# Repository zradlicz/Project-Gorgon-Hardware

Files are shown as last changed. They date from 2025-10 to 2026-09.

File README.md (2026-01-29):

# SDI-12 Underground Temperature Sensor

A 7-channel 4-wire RTD temperature measurement device that communicates via the SDI-12 protocol, designed for underground temperature profiling applications.

## Overview

This device is an SDI-12 sensor that provides high-precision temperature measurements from seven 4-wire RTD (Resistance Temperature Detector) inputs. It is designed for underground temperature sensing applications such as soil temperature profiling, permafrost monitoring, and geothermal studies. The 4-wire RTD configuration eliminates lead resistance errors, enabling accurate measurements even with long cable runs to buried sensors.

Built around the Raspberry Pi RP2040 microcontroller and featuring a 24-bit ADC, the sensor integrates seamlessly with existing SDI-12 data logger infrastructure.

## Features

- **7 channels** of 4-wire RTD temperature measurement
- **24-bit precision ADC** (AD7124-8) for high-resolution measurements
- **8-channel analog multiplexer** (ADG708) for RTD channel selection
- **SDI-12 protocol** compatible with standard environmental data loggers
- **RP2040 microcontroller** (dual-core Arm Cortex-M0+)
- **USB interface** for configuration and direct data access
- **128Mb flash memory** for configuration storage
- **Weatherproof enclosure** with gasket seal for field deployment

## Hardware Specifications

| Parameter | Value |
|---|---|
| RTD Channels | 7 (4-wire configuration) |
| ADC Resolution | 24-bit |
| Communication | SDI-12, USB |
| Power Supply | 5V |
| Logic Level | 3.3V (internal) |
| MCU | RP2040 (Raspberry Pi) |

## Key Components

| Reference | Part | Description |
|---|---|---|
| U7 | RP2040 | Main microcontroller |
| U8 | AD7124-8BCPZ | 24-bit 8-channel ADC |
| U5 | ADG708BRUZ | 8-channel analog multiplexer |
| U4 | W25Q128JVS | 128Mb SPI flash memory |
| U3 | TXS0102DCT | Bidirectional level shifter |
| U2 | NCP1117-3.3 | 3.3V voltage regulator |
| U1 | LP2950-5.0 | 5V voltage regulator |

## Repository Structure

```
├── sdi12-analog-mux.kicad_sch    # KiCad schematic
├── sdi12-analog-mux.kicad_pcb    # KiCad PCB layout
├── sdi12-analog-mux.kicad_pro    # KiCad project file
├── sdi12-analog-mux.step         # 3D model of assembled PCB
├── CAD/
│   ├── assembly.FCStd            # FreeCAD full assembly
│   ├── bottom_housing.FCStd      # Bottom enclosure design
│   ├── PCB.FCStd                 # PCB model
│   └── enclosure/
│       ├── Bottom.stl            # 3D printable bottom housing
│       ├── Cover.stl             # 3D printable top cover
│       ├── Gasket.stl            # 3D printable gasket
│       ├── Gasket_Drawing.dxf    # Gasket cutting template
│       └── *.step                # STEP files for CAD import
└── production/
    ├── bom.csv                   # Bill of materials
    ├── positions.csv             # Component placement data
    ├── designators.csv           # Component designators
    └── netlist.ipc               # IPC netlist
```

## Applications

- Soil temperature profiling
- Permafrost and active layer monitoring
- Geothermal gradient measurement
- Agricultural soil monitoring
- Infrastructure temperature monitoring (roads, pipelines)
- Environmental research

## Manufacturing

Production files are located in the `production/` directory:
- **BOM**: `bom.csv` contains the complete bill of materials
- **Pick and Place**: `positions.csv` provides component placement coordinates
- **Gerbers**: Included in `sdi12-analog-mux.zip`

## Enclosure

The enclosure is designed for 3D printing and field deployment:
- Bottom housing with mounting features
- Top cover
- Gasket for weatherproof sealing
- Provisions for cable glands and ventilation

STL files for printing and STEP files for CAD integration are provided in `CAD/enclosure/`.

## Design Tools

- **PCB Design**: KiCad 8
- **Mechanical Design**: FreeCAD

## License

This project is open-source hardware.

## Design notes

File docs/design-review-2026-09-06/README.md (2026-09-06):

# Lab handoff: Gorgon design and power review

Start with [DIAGNOSIS.md](DIAGNOSIS.md) for the three-board power failure and [DESIGN-REVIEW.md](DESIGN-REVIEW.md) for the broader review. These are an investigation and proposed tests, not completed repairs or a qualified design release. No physical measurements were performed by the reviewing agent.

## User-confirmed observations

- Three Gorgons connect to **separate sensor ports on one SDI-12 Talon**. With all three connected, none powers reliably and the Talon's 12 V sometimes fails to rise.
- Replacing the logger with GEMS_010 did not resolve SDI-12 read/detect/power-init failures and sensor-power warnings.
- A one-mux logger configuration briefly worked. Its exact power/data sequencing is not available here.
- Each Gorgon has an added **1000 µF input capacitor**. This was needed because the Gorgon's 3.3 V rail failed to start even on an **independent 12 V supply**. Do not assume the Talon caused that original failure.
- The user identified **CL05A106MQ5NUNC** as the assembled capacitor in the C22 discussion. It is rated 6.3 V; C22 is across +12 V and GND in the schematic, PCB and production netlist. Confirm the assembly designator and physical board revision before rework.
- The user reports the latest Talon revision. The supplied repository documents v1.4; physical markings have not been inspected.
- Four additional builds and outdoor installation before freeze in Thief River Falls are time-sensitive. A year-end deliverable is not the installation deadline.
- The changed antenna reportedly worsened cellular connectivity; no causal link to the power failure has been established.

## First lab session

1. Record physical revisions, all existing rework, fitted C22/C1 parts, deployed firmware/configuration, supply settings, and cable lengths. Photograph the regulator area if useful.
2. With power disconnected and capacitors discharged, confirm C22 continuity to J4 pin 1 (+12 V) and J4 pin 3 (GND). Replace the underrated part before further 12 V qualification; adding capacitance in parallel does not correct its voltage rating.
3. On a corrected board, compare startup with appropriate local ceramic bypassing and with the 1000 µF workaround. Capture U6 VIN and 3.3 V simultaneously, USB disconnected. A supply display is not a startup waveform.
4. Then capture Talon input 3.3 V, raw 12 V at C9, port output voltage and relevant faults during single, simultaneous-three and staged-three startup. The detailed report distinguishes the fault polarities and supply stages.
5. Validate the separate analog and firmware findings in the overall review. Do not assume every source-code finding describes the deployed binary, or that fixing power alone qualifies measurement accuracy.

For each trial, record board ID, firmware revision, exact wiring/rework, supply voltage/current limit, probe nodes, test action, captured waveform filenames, outcome and interpretation. Preserve raw measurements and distinguish observation from hypothesis. Add lab results to a new dated note alongside these reports so the original review remains traceable.

## Folder arrangement on the lab computer

Keep these repositories as siblings under any parent directory:

```text
gorgon/
  Project-Gorgon-Hardware/
    docs/design-review-2026-09-06/  <-- this handoff
  Project-Gorgon-Firmware/
  Talon-SDI12/
  Project-Kestrel/
  kistack/                       <-- optional local KiCad skills
```

Relative links in the reports follow that arrangement. Historical paths embedded in KiCad's generated reports/netlist describe the review machine; they need not exist on the lab computer. The exported PNG/SVG files are directly viewable. `render-detail.cjs` is an optional crop renderer and requires Node.js with `sharp` available; the PNG is already included.

## Source revisions reviewed

| Repository | HEAD at handoff preparation |
|---|---|
| Project-Gorgon-Hardware, before this documentation commit | `8b84860ecc22e27c8c2fa7a2cfa7f66302e375bf` |
| Project-Gorgon-Firmware | `efc0b9da459f3705718986a0e039e167b8b92fd8` |
| Talon-SDI12 | `10fa75d569e4cc0d9df58e523539647c02b93214` |
| Project-Kestrel | `4531bba269e10d33e8866283889c40a0a308d147` |

The reviewing tools used KiCad 10.0.6. DRC and ERC reports contain unresolved findings; no fabrication release was produced. Hardware repository user settings (`.kicad_prl`) were modified in the working directory and intentionally excluded from the documentation commit.

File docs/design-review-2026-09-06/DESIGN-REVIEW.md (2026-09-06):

# Gorgon design review

2026-09-06. Review of the local schematic, PCB, production netlist/BOM, firmware and calibration tool. Hardware observations apply to this checkout, not an independently inspected physical assembly. C22's fitted part number was supplied by the user. The deployed firmware version is unknown. No circuitry or firmware was modified.

## Overall assessment

The architecture is sensible: an AD7124-8 with differential four-wire RTD sensing, a shared excitation source, analog channel selection, input filtering, and an RP2040 for communication and calibration. The buck supply and external ADC are appropriate building blocks. The implementation is still at prototype maturity: there are confirmed component and firmware defects, an analog headroom problem, and unqualified field interfaces. I would not replicate the existing design unchanged for the four additional units.

Priority definitions: P1 = resolve before field qualification/build replication; P2 = resolve or explicitly qualify before deployment. Findings distinguish direct file evidence from inferred physical behavior.

## 1. P1 — C22 is overvolted: confirmed

C22 pad 1 is +12V and pad 2 is GND in schematic, PCB and production netlist. The supplied assembly part CL05A106MQ5NUNC is rated 6.3 V. Replace it; a parallel 1000 µF capacitor does not reduce its DC voltage. Specify a qualified 25 V ceramic retaining adequate capacitance under bias and temperature, with a suitable footprint. Audit C1 and other rail capacitors against the real assembly order. This is a confirmed rating violation; actual damage and its contribution to startup have not been measured. [Samsung specification](https://mm.digikey.com/Volume0/opasdata/d220001/medias/docus/41/CL05A106MQ5NUNC_Spec.pdf).

The 1000 µF workaround and three-unit Talon startup require requalification after this repair. See [power diagnosis](DIAGNOSIS.md). Preserve controlled inrush if substantial bulk capacitance remains necessary.

## 2. P1 — Excitation/reference network has insufficient margin at 500 µA

Verified current path: U8 AIN0/IOUT → U5 mux → RTD excitation lead → RTD → return diode D2–D8 → R19 5.11 kΩ → R20 250 Ω → GND. The firmware selects 500 µA at `sdi12-analog-mux.c:347`.

For a 100 Ω RTD, resistor drops alone total:

`0.0005 × (5110 + 250 + 100) = 2.73 V`.

At a nominal 3.3 V supply, the AD7124 specified current-source compliance ceiling is 2.93 V. Only **0.20 V** remains for the diode, mux, and both excitation leads. The documented 1N4148 diode replacement is very likely to exceed that allowance by itself at this current. Actual voltages need measurement; current can fall out of regulation, changing common-mode/reference conditions. A ratiometric architecture does not excuse violation of those limits.

Reducing current alone is not a complete fix: R20 lifts REFIN− only to 125 mV at 500 µA, 62.5 mV at 250 µA, and 12.5 mV at 50 µA. The code enables the reference buffers, whose lower limit is 100 mV above ground. At 50 µA, R19 develops only 0.2555 V differential reference, below the ADC's 0.5 V minimum. Thus the README's 50 µA operating description is not a valid setting for this buffered circuit as drawn.

Redesign the reference resistance, ground-lift resistance, excitation current and diode/mux topology together. Verify headroom at cold diode voltage, supply minimum, RTD maximum resistance, and longest lead resistance. Do not specify a replacement operating current without that calculation. [AD7124 datasheet, reference and current-source limits](https://www.analog.com/media/en/technical-documentation/data-sheets/ad7124-8.pdf).

## 3. P1 — Firmware turns processor temperature into RTD gain error: confirmed

`ad1724.c:309–354` treats the RP2040 temperature sensor as a fixed 0.706 V source, estimates AVDD from it, and stores `g_vref_correction`. At line 518, that factor multiplies measured RTD resistance. The sensor voltage depends on temperature and device variation, so this cannot independently measure AVDD. [RP2040 datasheet, section 4.9.5](https://datasheets.raspberrypi.com/rp2040/rp2040-datasheet.pdf).

Illustrative calculation at constant true supply: using the nominal sensor slope, a 10°C increase lowers its voltage from 0.706 V to 0.68879 V. The correction increases by `0.706/0.68879 = 1.025`. Applied to 100 Ω, that is about 2.5 Ω, approximately 6.5°C equivalent near 0°C. This is an illustration, not measured field error. Because the factor is calculated at startup, reboot temperature can change the calibration scale.

Remove or replace this correction after fixing the analog operating point and then recalibrate. If rail measurement is needed, use an actual known reference/supply-monitor method. Test precision resistors while changing board temperature separately from sensor temperature.

## 4. P1 — REFOUT is tied to the external reference sense node

Both the PCB and schematic join U8 pin 22 (REFOUT) to pin 12 (REFIN1+) on `POSITIVE_REF`, also connected through R29 to R19. This is not necessary for internally selected reference operation. `adc_read_internal_temperature()` enables the internal reference (`ad1724.c:595`), so diagnostic mode can drive a node intended to sense the external current-derived reference. The reference-measurement helper also enables it. Consequences depend on the active excitation and settling; this is a verified connection and mode interaction, not a measured contention current.

Separate REFOUT from the external reference sense network and retain its required local decoupling. Test RTD → internal-temperature → RTD transitions, including failures/timeouts. [AD7124 reference documentation](https://www.analog.com/media/en/technical-documentation/data-sheets/ad7124-8.pdf).

## 5. P1 — SDI-12 measurement acknowledgment is late: confirmed

`sdi12.c:315` calls the measurement callback before sending `atttn`. The RTD callback includes a 20 ms delay, three discarded conversions and eight averaged conversions (`sdi12-analog-mux.c:218` onward). The delay alone exceeds the permitted response-start time; sending `time_seconds = 0` after finishing does not fix this.

Send the acknowledgment promptly with an appropriate completion time, then measure asynchronously and return stored results when requested. Use a logic analyzer to validate break handling, initial response timing, line release, and data readiness. A tolerant bench logger does not establish compatibility with the Talon logger. [SDI-12 specification, section 4.4 and timing](https://www.sdi-12.org/current_specification/SDI-12%20Specification%201.4%20February%2020%202023.pdf).

## 6. P1 — TXS0102 is not a complete SDI-12 physical interface

U3 B1 directly connects to the field data terminal; OE is permanently tied high. The translator has internal pull-ups and edge accelerators. There is no explicit SDI-12 source-impedance or controlled-slew network in that connection, nor a defined receive/off-state resistance to ground. Putting the MCU GPIO in input mode does not disable U3's internal pull-ups. This is a design-level compatibility concern, independent of the missing power rail.

SDI-12 specifies 1–2 kΩ transmitter source resistance, 160–360 kΩ off resistance to ground, and limited slew rate. The current circuit does not deliberately implement those properties. Redesign around a controlled transmitter and receiver with defined idle/released states; qualify it using actual cable capacitance and powered/unpowered combinations. Do not base qualification on a generic UART speed rating. [TXS0102 datasheet](https://www.ti.com/lit/ds/symlink/txs0102.pdf), [SDI-12 electrical specification](https://www.sdi-12.org/current_specification/SDI-12%20Specification%201.4%20February%2020%202023.pdf).

## 7. P1 — Calibration tool and firmware disagree: confirmed

The firmware calibration callback explicitly uses **5030 Ω** (`sdi12-analog-mux.c:127`). The Python tool reads an existing NVM value and computes `new = old × actual/measured` (`calibrate.py:54,570`). That formula is incorrect when the firmware used 5030 rather than `old`; repeated calibration can alter gain even with identical hardware and reference resistors. Align the assumed scale and add a repeated-calibration check.

The tool also writes one averaged value to every channel (`calibrate.py:324`), whereas acquisition applies per-channel values. Save individually determined channel constants if channel correction is intended. The hardware R19 nominal is 5110 Ω, while firmware defaults are 5030 Ω; explain or eliminate that discrepancy instead of leaving conflicting nominal values.

Historical evidence: `calibration_report_007_20260306_144608.txt` shows approximately 99.8 Ω standards producing about 108 Ω, followed by an averaged effective reference of 4677.01 Ω. This is much larger than R19's stated 0.1% tolerance and cannot be attributed to that tolerance alone. The report may precede the current firmware, so it does not identify which current defect caused the historical error. Room-temperature gain correction cannot establish cold accuracy.

## 8. P2 — Internal ADC temperature conversion is incorrectly decoded

`ad1724.c:633–646` sign-extends the ADC result as two's complement. Bipolar output is offset binary; the documented temperature equation subtracts `0x800000` before division. Correct decoding and verify using a representative raw code. This affects diagnostic temperature, not directly the external RTD conversion. [AD7124 temperature equation](https://www.analog.com/media/en/technical-documentation/data-sheets/ad7124-8.pdf).

## 9. P2 — USB and field power are connected without explicit source arbitration

U2's USB-fed 3.3 V output and U6's buck output are directly joined. The schematic contains no explicit ORing or power mux. Their behavior with USB only, 12 V only, both supplies, and either supply removed must be qualified against actual fitted regulators, including reverse-current behavior. This is a verified shared connection, not proof of harmful current on every board.

Prefer explicit power selection/ORing or a documented exclusive-power service arrangement. USB-only operation also does not power U1's 5 V SDI-12 rail; do not assume USB debugging reproduces field behavior.

## 10. P2 — Outdoor connector protection is incomplete

J4 feeds the power converters directly and feeds U3 directly on data. No dedicated reverse-polarity protection, input fuse/current-limiting stage or connector TVS network is present in the Gorgon netlist. The RTD sense inputs have useful 1 kΩ/filter networks, but excitation leads connect to mux pins without a complete connector surge-protection scheme. The return-path diodes are not a substitute for a field transient-protection design.

Define expected miswiring/ESD/surge exposure, then add protection consistent with the ADC leakage budget and regulator voltage limits. The nominal 17 V buck input ceiling leaves little room above a 16 V SDI-12 supply for transients. Protection should be validated rather than merely adding a TVS whose clamping voltage exceeds the protected part's limit.

## Layout, manufacturing and maintainability

The schematic visually groups functional blocks well. The MCU has its core regulator capacitors, clock, flash, USB series resistors and debug interfaces. The buck has nearby input/output components and substantial local copper/vias; this review did not establish a broken buck connection. ADC filtering and the separate differential sense leads are useful foundations. Ratiometric sensing reduces sensitivity to excitation variation within valid operating conditions.

However, the production BOM leaves most exact part numbers blank, including capacitor voltage/bias characteristics, reference-resistor temperature coefficient, inductor saturation current, and some regulator identity. D2–D8 remain generic `D_Schottky` in the design despite the documented 1N4148 assembly rework. This is a repeatability problem: the built circuit is not completely specified by the CAD/BOM.

KiCad 10.0.6 DRC: **148 violations, zero unconnected items**. Thirty are ADC footprint clearances (0.1651 mm versus a 0.2 mm local rule); these need assessment against actual footprint/manufacturer capability, not an assumption of 30 shorts. Most other messages concern library mismatches/missing libraries and silkscreen constraints.

ERC: **157 messages: 28 errors and 129 warnings**. Many reflect imported unspecified pin types, unused pins and library configuration, but the check is not clean. Repair symbol electrical types and review every meaningful connectivity error before release. Counts are not counts of proven hardware failures. This review used exported schematic imagery, board/netlist cross-checks, the earlier regulator copper render, and these rule reports; it is not a completed EMI, thermal, enclosure ingress, or production qualification.

For the next revision, preserve a continuous return plane, keep switching current loops away from ADC/reference routing, specify reference-resistor drift, add accessible rail/reference test points, and retain reset/debug access. Verify analog noise and accuracy with USB disconnected and during logger radio activity. More digital filtering cannot remove systematic gain/reference errors.

## Recommended order for the four builds

1. Correct C22 and audit the complete assembled BOM. Qualify single-board startup, then three-unit startup from discharged capacitors.
2. Resolve excitation/reference headroom and REFOUT routing on one prototype. Measure AIN0, REFIN+/− and RTD input common-mode at operating extremes.
3. Correct the temperature-derived gain correction, calibration contract, and SDI-12 acknowledgment timing; validate repeated calibration and command sequences.
4. Qualify or revise the SDI-12 physical interface, power-source interaction and field protection.
5. Freeze one hardware/BOM/firmware/calibration combination. Validate all seven channels at multiple resistance/temperature points, with board temperature varied independently, intended cables, minimum supply and cold starts. Record an accuracy requirement first; a 24-bit ADC is not an accuracy specification.
6. Build the four copies only against that qualified combination. A staggered Talon startup may recover current units, but it cannot qualify temperature accuracy or correct C22's voltage rating.

## Local evidence

- [Power investigation](DIAGNOSIS.md)
- [Schematic image](gorgon-schematic.png)
- [Exported netlist](gorgon-review-netlist.xml)
- [DRC report](gorgon-drc.rpt)
- [ERC report](gorgon-erc.rpt)
- [Firmware ADC driver](../../../Project-Gorgon-Firmware/ad1724.c)
- [Main application](../../../Project-Gorgon-Firmware/sdi12-analog-mux.c)
- [SDI-12 implementation](../../../Project-Gorgon-Firmware/sdi12.c)
- [Calibration tool](../../../Project-Gorgon-Firmware/calibration/calibrate.py)

No bench tests or firmware execution on physical hardware were performed. Confirm deployed firmware and physical rework before attributing field symptoms to a particular source-code finding.

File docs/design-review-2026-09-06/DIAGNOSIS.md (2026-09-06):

# Three-Gorgon / SDI-12 Talon power investigation

2026-09-06. Scope: local Gorgon schematic and PCB, Gorgon firmware, Talon SDI-12 Eagle schematic and board / v1.4 production BOM, and Kestrel Eagle schematic and board / v1.9 BOM. User confirms separate Talon sensor ports, a 1000 µF capacitor on each Gorgon, and latest Talon revision. The latest Talon revision in these files is v1.4; verify physical markings before rework.

## Finding

**Confirmed component-selection defect, based on the supplied C22 assembly part:** Samsung **CL05A106MQ5NUNC is 10 µF, 6.3 V, ±20%, X5R, 0402**. C22 is connected across 12 V, about 1.9 times its rated voltage. It is unsuitable at this location and must be replaced before further 12 V qualification. The 1000 µF parallel rework does not reduce its applied DC voltage. This establishes an overvoltage condition, not proof of the exact physical failure mechanism or that it alone explains every symptom. Source: [Samsung specification sheet](https://mm.digikey.com/Volume0/opasdata/d220001/medias/docus/41/CL05A106MQ5NUNC_Spec.pdf).

**Updated evidence:** The user confirms that, before the 1000 µF rework, Gorgon's 3.3 V failed to start even from an independent 12 V supply. The Talon therefore cannot explain that original failure. Treat the investigation as two potentially interacting problems: Gorgon input/regulator startup, followed by shared Talon startup with the added capacitors. A bench supply does not establish that voltage was stable at U6 during startup; lead impedance and supply current limiting remain possible.

**The leading explanation is a startup power/protection interaction: three 1000 µF input capacitors and three boards load a single shared boost converter.** Separate sensor ports do not provide independent 12 V supplies. Either the shared supply collapses, its upstream switch trips, or individual port protection latches off. A wrong Kestrel supply-mode sequence can exacerbate this dramatically.

The design and reported symptoms support this diagnosis, but there is no oscilloscope trace or field firmware/configuration here to identify the first component that trips. Do not treat a particular failed component as proven. A bad cable or one excessive-load board can also trigger the common supply failure.

## Verified circuit evidence

| Stage | Actual circuit in the local files | Implication |
|---|---|---|
| Kestrel main Talon supply | U15 MIC22602 supplies `3V3_BULK+`; U30 TCK111G passes it to `3V3_TALON+` when `3V3_AUX_EN` is high | Main supply must be active for the sensor load |
| Kestrel standby Talon supply | U31 FPF2195BUCX feeds the same rail from `3V3_CORE`; U32 inverts `3V3_AUX_EN`; R68 is 5.6 kΩ | Standby is approximately 100 mA at 3.3 V. This is a separate, much smaller budget |
| Kestrel daughterboard protection | Each Talon connector has AP2411 (`P1:U4` through `P4:U4`) before its 3.3 V output | One switch feeds the entire SDI-12 Talon, including all its sensor ports; a trip removes power from all of them |
| Talon shared boost | U8 is populated as LM2623AMM/NOPB, despite the LM2621 library symbol; L1 6.8 µH, D2 CDBA3100, C9 100 µF; R24 115 kΩ and R25 13.3 kΩ set about 11.96 V | One 3.3 V-to-12 V converter serves Q5–Q8, not one converter per connector |
| Talon sensor port protection | Q5/Q6/Q7 feed R5/R6/R7 (82 mΩ), then J3/J4/J5. U4 INA4180A2 gain 50, U5 MAX9034, D1 2.048 V reference, U2 CD4044 latch | Nominal per-port trip is 2.048 / (50 × 0.082) = **0.4995 A**. This is a latching cutoff, not a controlled capacitor-charging current source |
| Talon transient filtering | C17–C20 are DNP; R35–R38 are 1 kΩ | No populated capacitor provides an intentional RC delay at those comparator inputs; a sufficiently long charging transient can latch a port off |
| Gorgon input | J4 pin 1 = +12 V, pin 2 = data, pin 3 = GND. C1 1 µF and C22 10 µF are directly across input. Added 1000 µF capacitors are documented rework | The three field capacitors total 3000 µF, plus on-board capacitance |
| Gorgon regulators | U6 `XPS629210DRLR` has VIN and EN tied to +12 V and supplies +3V3; U1 makes +5 V for the translator. U2 supplies +3V3 from USB VBUS | MCU load starts as input rises. USB can mask the field power failure; baseline testing should have USB disconnected |

These power connections were checked against the Gorgon PCB pad nets and Talon Eagle board signals, not just README descriptions. The Gorgon schematic was exported with KiCad and visually inspected. This is a targeted power review, not a complete ERC/DRC or production release.

## Why the capacitors matter

For the three added capacitors, C = 0.003 F. Charging them to 12 V requires Q = CV = **0.036 coulomb** and stored energy E = ½CV² = **0.216 J**, before running the boards.

Illustrative linear ramps, not measured waveforms:

| Time to reach 12 V | Charging current per Gorgon | Combined 12 V charging current |
|---|---:|---:|
| 10 ms | 1.2 A | 3.6 A |
| 100 ms | 0.12 A | 0.36 A |

At 85% assumed boost efficiency, 0.36 A at 12 V requires about **1.54 A at 3.3 V near the end of the ramp**, before board operating current and other Talon loads. For a single 1000 µF capacitor, charging under 0.5 A needs at least 24 ms even with zero operating load. The existing port switches do not enforce such a ramp.

The AP2411 is rated for 2 A continuous load with a typical 2.5 A current limit and approximately 7 ms fault blanking/latch time; actual thresholds and timing vary. The LM2623 switch-current rating is an inductor/switch peak rating, not available 12 V output current. Thus comparing three Gorgon currents directly with the boost's advertised ampere figure is invalid. See [AP2411 datasheet](https://www.diodes.com/datasheet/download/AP2411.pdf) and [LM2623 datasheet](https://www.ti.com/lit/ds/symlink/lm2623.pdf).

The standby branch deserves explicit verification: [FPF2195 datasheet](https://www.onsemi.com/download/data-sheet/pdf/fpf2194-d.pdf) gives about 100 mA with 5.516 kΩ, close to the installed 5.6 kΩ. Even an ideal 3.3 V, 100 mA source only represents 27.5 mA at 12 V; conversion losses and other loads reduce that. This is not adequate evidence of main-power capacity simply because a meter initially reads 3.3 V.

The hardware README's extra capacitor can help local transient stability after startup while worsening the initial load seen by the Talon. Removing all input capacitance is not a qualified fix. The firmware README's 130 mA statement is not a measurement of these installed units or the Talon's actual hardware trip threshold.

## Decisive bench test

### First resolve the independent-supply startup failure

The repository BOM specifies **C22 = 10 µF, 0402**, with no manufacturer part number, voltage rating or dielectric. The user subsequently supplied **CL05A106MQ5NUNC** as the assembled capacitor. Its 6.3 V rating is insufficient for C22's 12 V connection. Remove that part and replace it with a qualified higher-voltage ceramic; do not leave it in parallel with the replacement. Treat previously overstressed capacitors as suspect even if a low-voltage capacitance check looks normal. Actual breakdown, leakage or loss of capacitance has not been measured, and the 1000 µF rework's success does not establish which mechanism caused the original startup failure.

For the four additional builds, specify an exact manufacturer part number, voltage rating, dielectric and effective capacitance requirement for C22. A 25 V X7R/X5R ceramic selected to retain at least 3 µF at 12 V over tolerance/temperature is the target; use a larger footprint if required. Audit other capacitors on the 12 V rail, including C1, against the assembly order. Do not infer that use of this same 6.3 V part on a lower-voltage rail is automatically wrong. After correcting C22, test one board without the 1000 µF workaround under controlled conditions; then reassess whether all three boards still need bulk capacitance and whether the Talon startup problem remains.

The TPS629210 datasheet specifies at least 3 µF effective input capacitance, recommends 4.7 µF nominal in most applications, and requires a close VIN-to-GND connection. Its capacitor examples include 25 V parts. The PCB places C22 about 1.6 mm above U6 VIN, with local copper and a ground-via array; this inspection did not establish an open connection or an obvious pin-assignment error. R8 = 154 kΩ and R7 = 34 kΩ set approximately 3.318 V. R12 = 9.31 kΩ selects 2.5 MHz forced PWM with external feedback; that is a valid configuration. Source: [TPS629210 datasheet, sections 7.3, 8.3 and 9.2.2.3.3](https://www.ti.com/lit/ds/symlink/tps629210.pdf).

On one controlled bench unit, compare startup without the added electrolytic against startup with verified local ceramic decoupling selected to retain at least 3 µF at 12 V across tolerances and temperature. Use a suitably rated part (25 V is a reasonable starting rating, subject to its bias curve) and short connections at U6; long flying leads do not test local high-frequency bypassing. Retain the existing field rework until this replacement is validated.

Capture U6 VIN pin 6 relative to its GND pin 5, and +3V3 at C11 simultaneously, using short probe ground connections. USB should be disconnected. Record bench-supply current limit and test both supply-enable startup and application of already-live 12 V using short leads. VIN dips/restarts indicate input/source interaction; a clean VIN with failed VOUT moves the investigation to U6, feedback, output capacitance, load and assembly. Ringing can be damped by electrolytic ESR as well as capacitance, so success with 1000 µF does not prove that this much stored energy is required.

### Then identify the Talon failure stage

Use the installed cables, USB disconnected, and capture startup on a scope. Discharge capacitors through a suitable resistor between trials and verify discharged voltage; do not directly short them. If available, capture current with a current probe or properly installed shunt.

1. With sensor outputs off, enable Kestrel `3V3_AUX_EN` and verify `3V3_AUX_PG`, the main 3.3 V rail, and Talon input. Verify Talon C9 reaches approximately 12 V with no sensor outputs enabled.
2. Enable Talon `SENSE_EN`, allow its 3.3 V sense supply and 2.048 V reference to settle, and hold all `EN1–EN4` low to reset their latches. Then enable one port. Repeat separately for each Gorgon and each suspect cable/port combination.
3. Start all three from discharged inputs using the current firmware. Compare that capture with a staged startup: enable one, wait for voltage and current to settle, then the second, then the third. An initial 0.5–1 s diagnostic spacing is reasonable; determine production timing from measured settling, not this trial value.
4. Keep all three on and perform measurements. If staged startup works but operation later collapses, investigate sustained demand and supply mode changes as well as inrush. If a particular board/cable causes failure regardless of position, isolate that load first.

| Probe/readout | Result | Interpretation |
|---|---|---|
| Talon J2 pin 2 / C3 positive to GND, plus Kestrel `!TALONx_FAULT` | 3.3 V disappears and upstream fault asserts low while upstream input stays sound | AP2411/common feed shutdown |
| Kestrel `3V3_AUX_EN`, `3V3_AUX_PG`, `3V3_TALON+` | Main supply never enabled or falls back to standby | Supply mode/firmware ordering or main supply fault |
| Talon C9 positive (raw 12 V), compared with 3.3 V input | 3.3 V holds but C9 voltage collapses | Shared boost overload/startup limitation, or a downstream excessive load |
| C9 holds near 12 V; J3/J4/J5 pin 1 fails and corresponding Talon `FAULT1/2/3` is high | Port shutdown | Per-port overcurrent latch; check inrush, wiring, and unit load |
| C9 and all port rails hold | Gorgon local +3V3 or communications fail | Continue at U6 output and then protocol/boot checks |

Talon `FAULT1–4` are active high; Kestrel `!TALONx_FAULT` is active low. Read faults while their logic supplies are valid. The sensor-port voltage ADC measures the switched output, so its result alone cannot distinguish a stopped boost from an open port switch. Scope C9 as well. Talon J2's pin numbering above is the PCB netlist numbering; confirm connector orientation before probing.

## Corrective direction

First test and enforce this logger sequence: **main Kestrel supply on and settled → Talon supply on → sensing on and settled → reset port latches → start ports one at a time → enable only the data path being polled.** Keep the main supply on whenever these sensors require it. A Talon port fault needs an EN low/reset followed by a controlled retry; a Kestrel AP2411 latch needs its own Talon enable reset. Capture faults before a retry and bound retries.

The supplied Talon demo explicitly states that `SENSE_EN` must precede port enables at `TalonSDI12SerialDemo.ino:364`, but the demo uses MCP23018 while the v1.4 board uses PCAL9535A. It is evidence of intended ordering, not a production-ready patch. The actual deployed logger firmware, GEMS_010 configuration and error logs are absent from these folders; changing Gorgon's MCU firmware cannot directly control the Talon's power switches.

If staged startup still trips individual ports, retain needed bulk capacitance behind a **controlled precharge/inrush-limiting circuit**, dimensioned from measured running current and capacitor charge demand. If all three exceed sustained capacity, provide a suitably rated regulated sensor supply. When using an external 12 V supply, disconnect Talon +12 V from the sensor feeds, retain common GND and the correct data connections, and provide branch protection. Do not parallel the external supply with the Talon boost output or simply increase/bypass the fault limits.

## Four additional builds

Qualify the supply/startup solution on the existing three before replicating the power arrangement. The field-ready acceptance test should include repeated fully discharged starts with three attached boards, the longest actual cable, low intended battery condition, cold operation at the intended deployment temperature, all 21 RTD readings, and logger wake/sleep and cellular transmission cycles. Start with 20 consecutive discharged-start trials per critical condition and a sustained logging run; this is an initial engineering acceptance target, not a demonstrated reliability rating.

For each new board: verify diode rework documented in the hardware README, input capacitor polarity/rating, 12 V/5 V/3.3 V rails, measured startup and running current, all seven channels, serial identity, calibration, and enclosure/cable sealing. Record the tested board revision and power solution. Plan installation ahead of local freeze based on the actual field schedule; the end-of-year deliverable is not the installation deadline.

## Independent communication issue

The supplied Gorgon application hard-codes address `0` (`sdi12-analog-mux.c:379`), and `sdi12.c:369` does not implement address change. If multiple data paths are enabled together, identical addresses can collide. Separate Talon ports can use the same address if firmware connects/polls only one data path at a time. The installation document's instruction to assign addresses via NVM is not implemented in this checkout. This explains possible read/detect failures after power is healthy, but not a missing 12 V rail.

The changed antenna is not established as the cause. Repeat rail captures during cellular transmission to see whether radio current worsens shared-supply margin; investigate RF performance separately once power is reliable.

## Evidence artifacts

- [Gorgon exported netlist](gorgon-review-netlist.xml)
- [Gorgon schematic image](gorgon-schematic.png)
- [Gorgon schematic SVG](sdi12-analog-mux.svg)
- [Hardware capacitor erratum](../../README.md)
- [Talon schematic](../../../Talon-SDI12/Hardware/Talon_SDI12.sch)
- [Kestrel schematic](../../../Project-Kestrel/Hardware/MainLogger.sch)
- [INA4180 gain specifications](https://www.ti.com/lit/ds/symlink/ina4180.pdf)
- [CD4044 latch specifications](https://www.ti.com/lit/ds/symlink/cd4044b.pdf)

No design files or firmware were modified, and no physical bench tests were performed in this investigation.

Follow-up layout check: KiCad reported 148 DRC violations and zero unconnected items in the current PCB. These findings do not diagnose an analog startup problem or validate the assembly. They need separate disposition before a new fabrication release. See `gorgon-drc.rpt`; `regulator-detail.png` shows the reviewed copper area. No fabrication outputs were released.

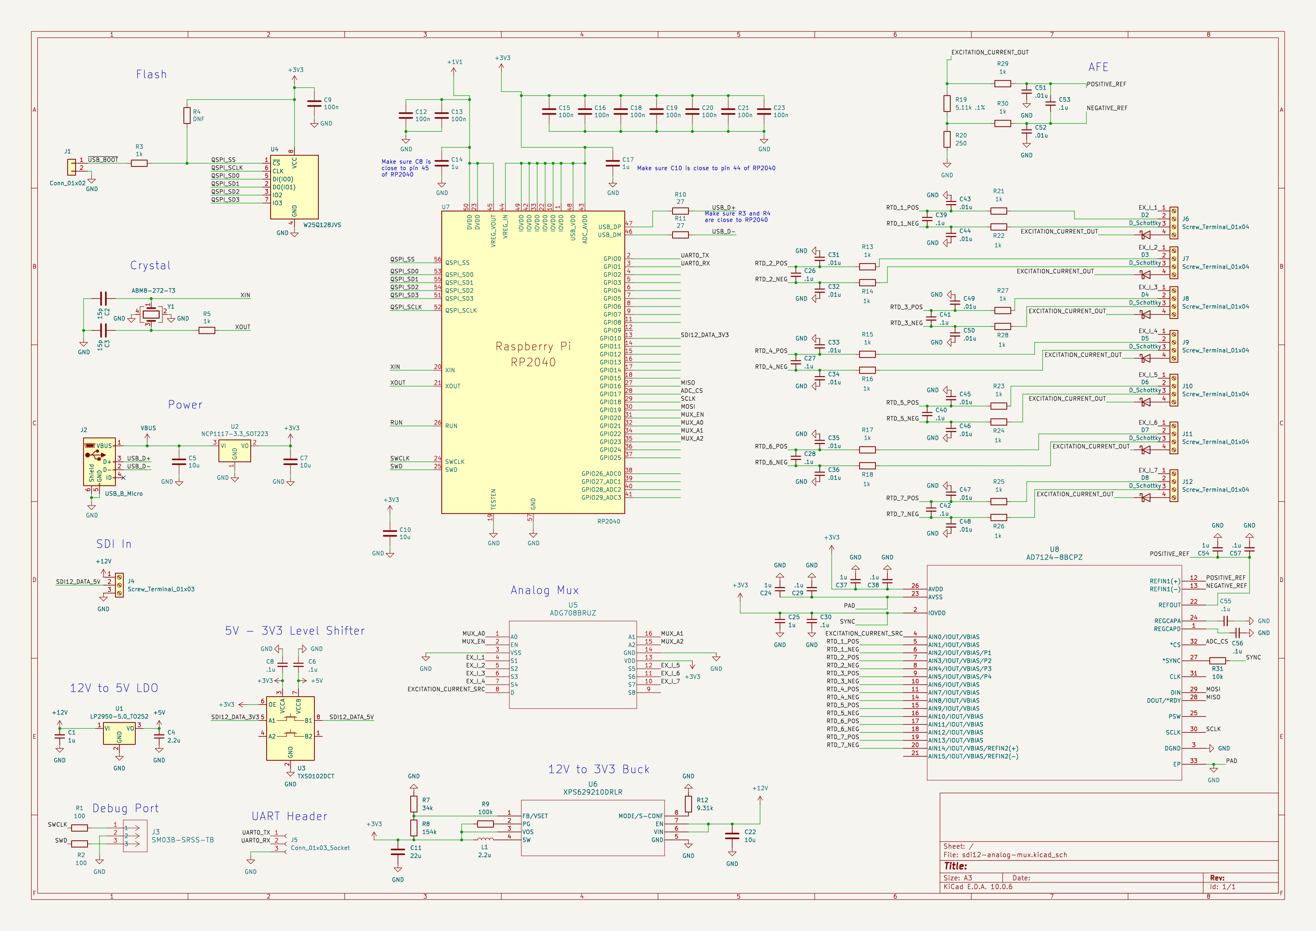
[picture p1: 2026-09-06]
docs/design-review-2026-09-06/gorgon-schematic.png

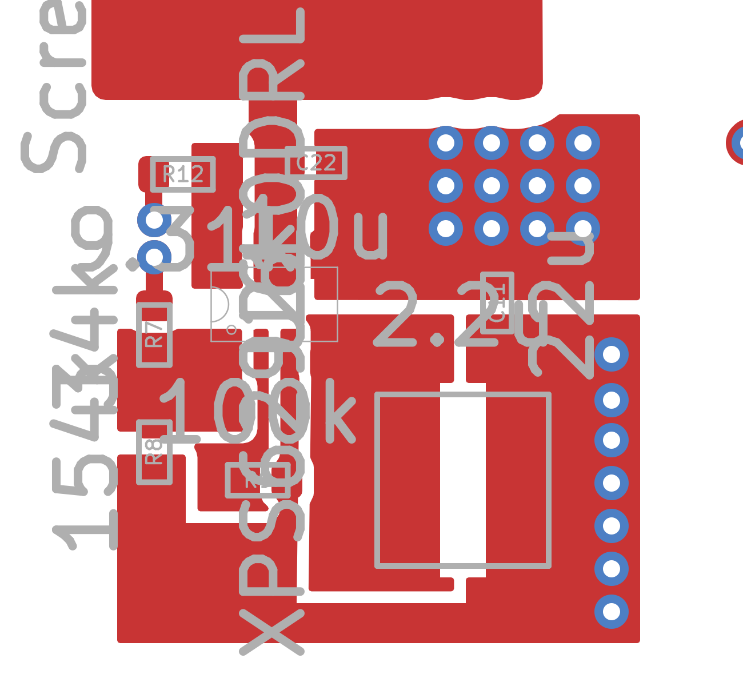
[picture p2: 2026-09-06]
docs/design-review-2026-09-06/regulator-detail.png

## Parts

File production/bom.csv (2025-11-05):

Designator | Footprint | Quantity | Value | LCSC Part #
C1, C24, C25, C37 | 0805 | 4 | 1u
C10, C5, C7 | 0805 | 3 | 10u
C11 | 0402 | 1 | 22u
C12, C13, C15, C16, C18, C19, C20, C21, C23, C9 | 0402 | 10 | 100n
C14, C17, C54 | 0402 | 3 | 1u
C2, C3 | 0402 | 2 | 15p
C22 | 0402 | 1 | 10u
C26, C27, C28, C29, C30, C38, C39, C40, C41, C42, C53, C55, C56, C57, C6, C8 | 0402 | 16 | .1u
C31, C32, C33, C34, C35, C36, C43, C44, C45, C46, C47, C48, C49, C50, C51, C52 | 0402 | 16 | .01u
C4 | 0402 | 1 | 2.2u
D2, D3, D4, D5, D6, D7, D8 | D_SOD-323F | 7 | D_Schottky
J1 | PinHeader_1x02_P2.54mm_Vertical | 1 | Conn_01x02
J10, J11, J12, J6, J7, J8, J9 | TerminalBlock_Xinya_XY308-2.54-4P_1x04_P2.54mm_Horizontal | 7 | Screw_Terminal_01x04
J2 | USB_Micro-B_Amphenol_10103594-0001LF_Horizontal_modified | 1 | USB_B_Micro
J3 | CONN_SM03B-SRSS-TB_JST | 1 | SM03B-SRSS-TB
J4 | TerminalBlock_Xinya_XY308-2.54-3P_1x03_P2.54mm_Horizontal | 1 | Screw_Terminal_01x03
J5 | PinHeader_1x03_P2.54mm_Vertical | 1 | Conn_01x03_Socket
L1 | WE-MAPI_3012 | 1 | 2.2u
R1, R2 | 0402 | 2 | 100
R10, R11 | 0402 | 2 | 27
R12 | 0402 | 1 | 9.31k
R13, R14, R15, R16, R17, R18, R21, R22, R23, R24, R25, R26, R27, R28, R29, R3, R30, R5 | 0402 | 18 | 1k
R19 | 0402 | 1 | 5.11k .1%
R20 | 0402 | 1 | 250
R31 | 0402 | 1 | 10k
R4 | 0402 | 1 | DNF
R7 | 0402 | 1 | 34k
R8 | 0402 | 1 | 154k
R9 | 0402 | 1 | 100k
U1 | TO-252-2 | 1 | LP2950-5.0_TO252
U2 | SOT-223-3_TabPin2 | 1 | NCP1117-3.3_SOT223
U3 | SSOP-8_2.95x2.8mm_P0.65mm | 1 | TXS0102DCT
U4 | SOIC-8_5.23x5.23mm_P1.27mm | 1 | W25Q128JVS
U5 | RU_16_ADI | 1 | ADG708BRUZ
U6 | SOT_9210DRLR_TEX-M | 1 | XPS629210DRLR
U7 | RP2040-QFN-56 | 1 | RP2040
U8 | CP_32_12_ADI-M | 1 | AD7124-8BCPZ
Y1 | Crystal_SMD_3225-4Pin_3.2x2.5mm | 1 | ABM8-272-T3

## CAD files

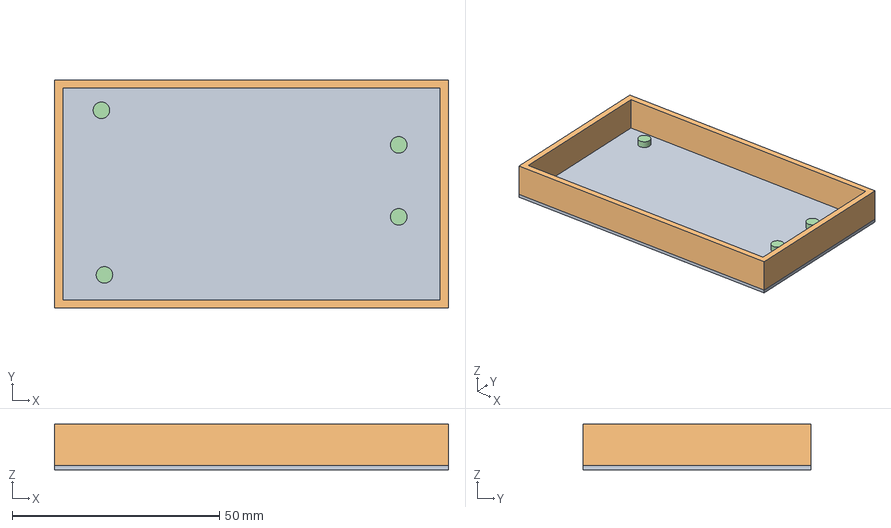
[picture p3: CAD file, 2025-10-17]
CAD/bottom_housing.FCStd
95.0 x 55.0 x 11.0 mm

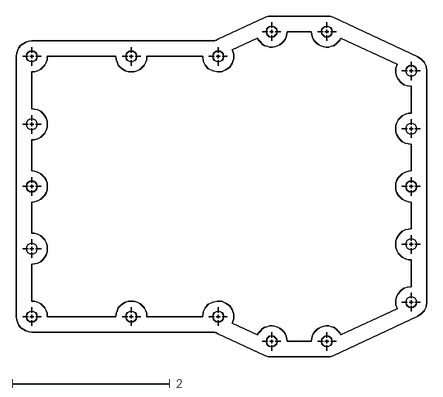
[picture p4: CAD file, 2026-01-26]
CAD/enclosure/Gasket_Drawing.dxf
5.20 x 4.32

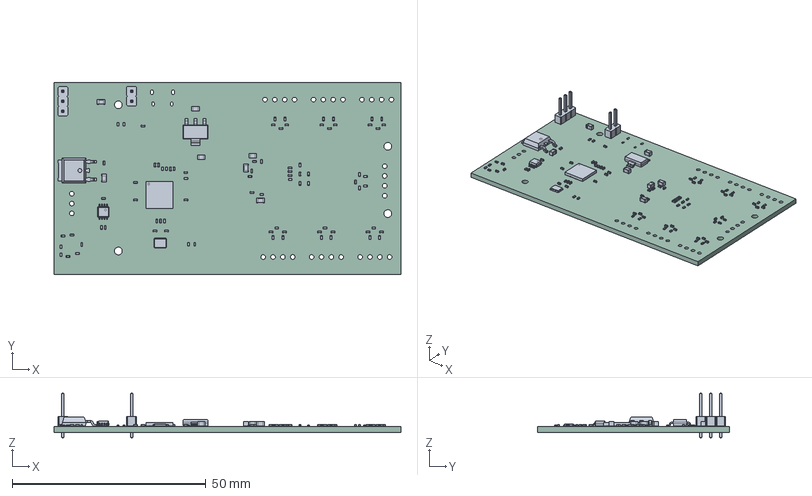
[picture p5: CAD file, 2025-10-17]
sdi12-analog-mux.step
89.5 x 49.5 x 11.5 mm
C_0402_1005Metric x 51
R_0402_1005Metric x 31
PinHeader_1x03_P2.54mm_Vertical
C_0805_2012Metric x 7
Crystal_SMD_3225-4Pin_3.2x2.5mm
SOT-223
SSOP-8_2.95x2.8mm_P0.65mm
PinHeader_1x02_P2.54mm_Vertical
sdi12-analog-mux 1.86.1
QFN-56-1EP_7x7mm_P0.4mm_EP5.6x5.6mm
sdi12-analog-mux_PCB

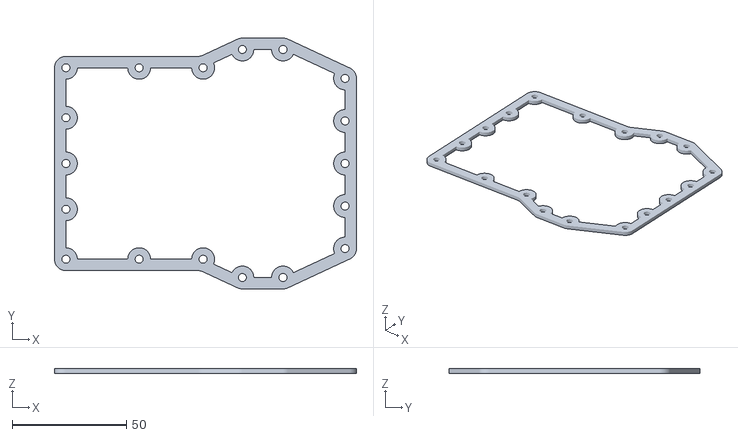
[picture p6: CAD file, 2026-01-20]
CAD/enclosure/Gasket.stl
132.0 x 109.7 x 2.00

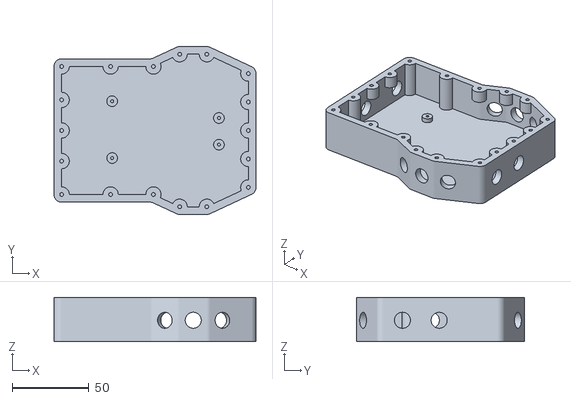
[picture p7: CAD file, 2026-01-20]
CAD/enclosure/Bottom.stl
132.0 x 109.7 x 29.0

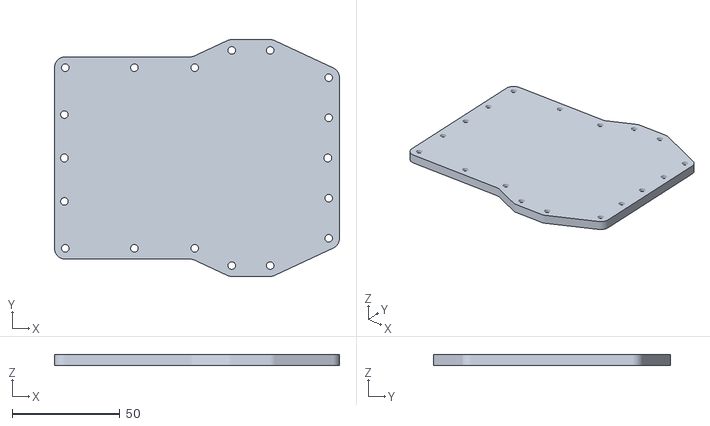
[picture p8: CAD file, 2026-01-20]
CAD/enclosure/Cover.stl
132.0 x 109.7 x 5.00

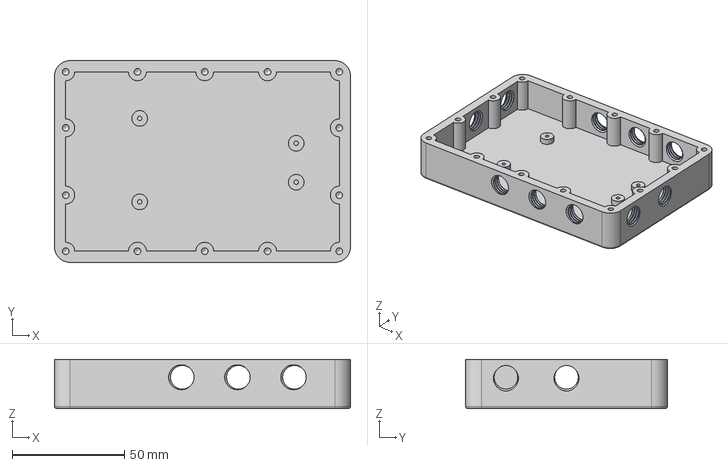
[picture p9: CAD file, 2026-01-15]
CAD/enclosure/bottom-enclosure v17.step
132.0 x 90.0 x 22.0 mm

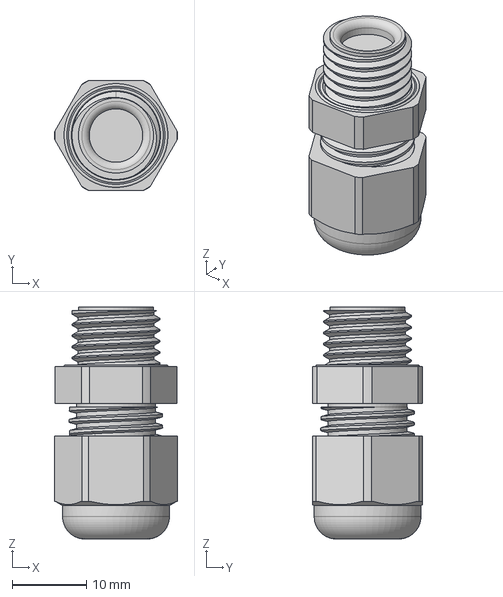
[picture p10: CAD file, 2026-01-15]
CAD/enclosure/c-1sng601012r0000-a-3d v1.step
16.6 x 14.9 x 31.3 mm

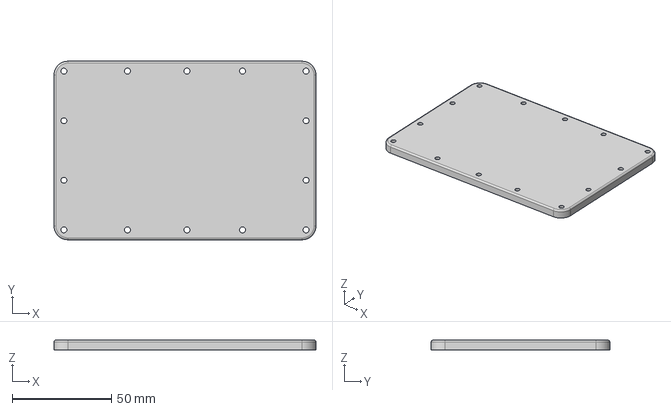
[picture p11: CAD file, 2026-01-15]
CAD/enclosure/top-enclosure v3.step
132.0 x 90.0 x 5.00 mm

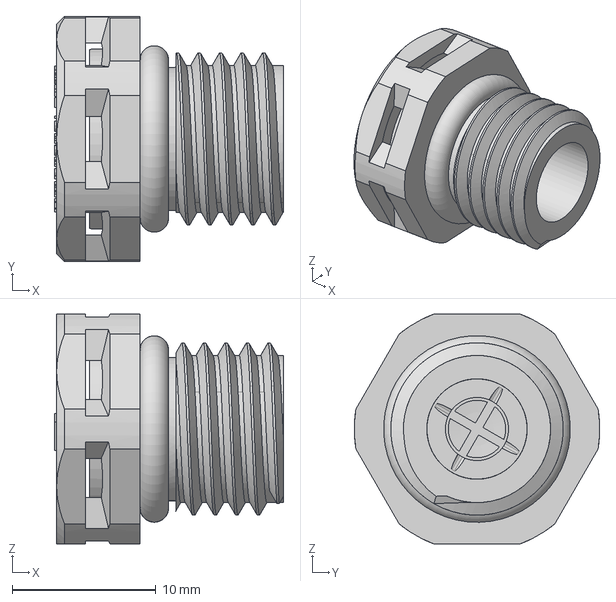
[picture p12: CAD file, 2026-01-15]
CAD/enclosure/VENT-PS1XXX-XXXXX-STP v1.step
16.0 x 17.1 x 16.0 mm

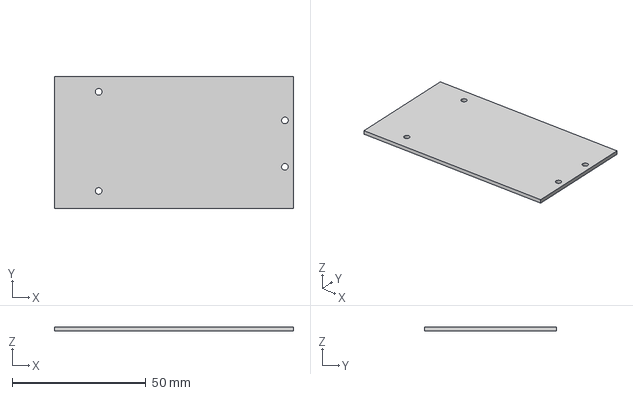
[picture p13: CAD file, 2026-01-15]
CAD/enclosure/pcb v1.step
89.5 x 49.5 x 1.60 mm

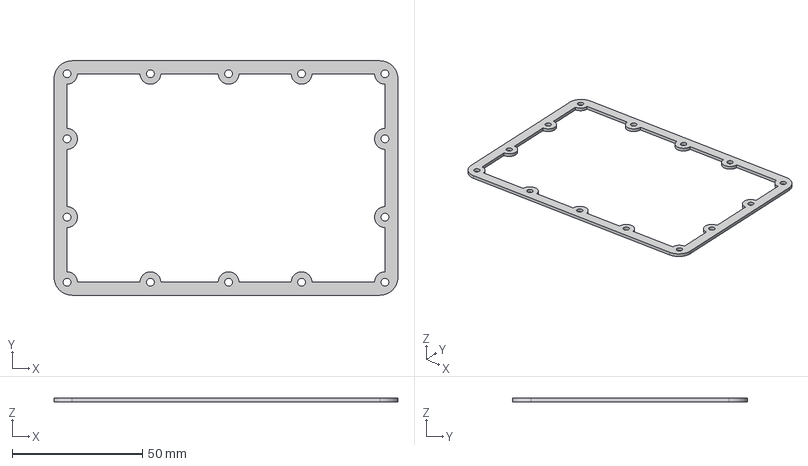
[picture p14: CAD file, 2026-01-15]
CAD/enclosure/gasket v4.step
132.0 x 90.0 x 1.50 mm

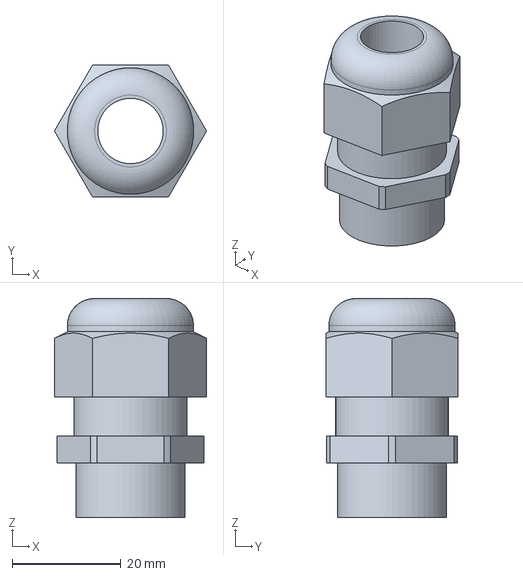
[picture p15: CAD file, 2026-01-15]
CAD/enclosure/1411133_G_INS_M20_S68N_PNES_BK-select v1.step
27.9 x 24.2 x 40.2 mm

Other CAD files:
CAD/assembly.FCStd
CAD/PCB.FCStd

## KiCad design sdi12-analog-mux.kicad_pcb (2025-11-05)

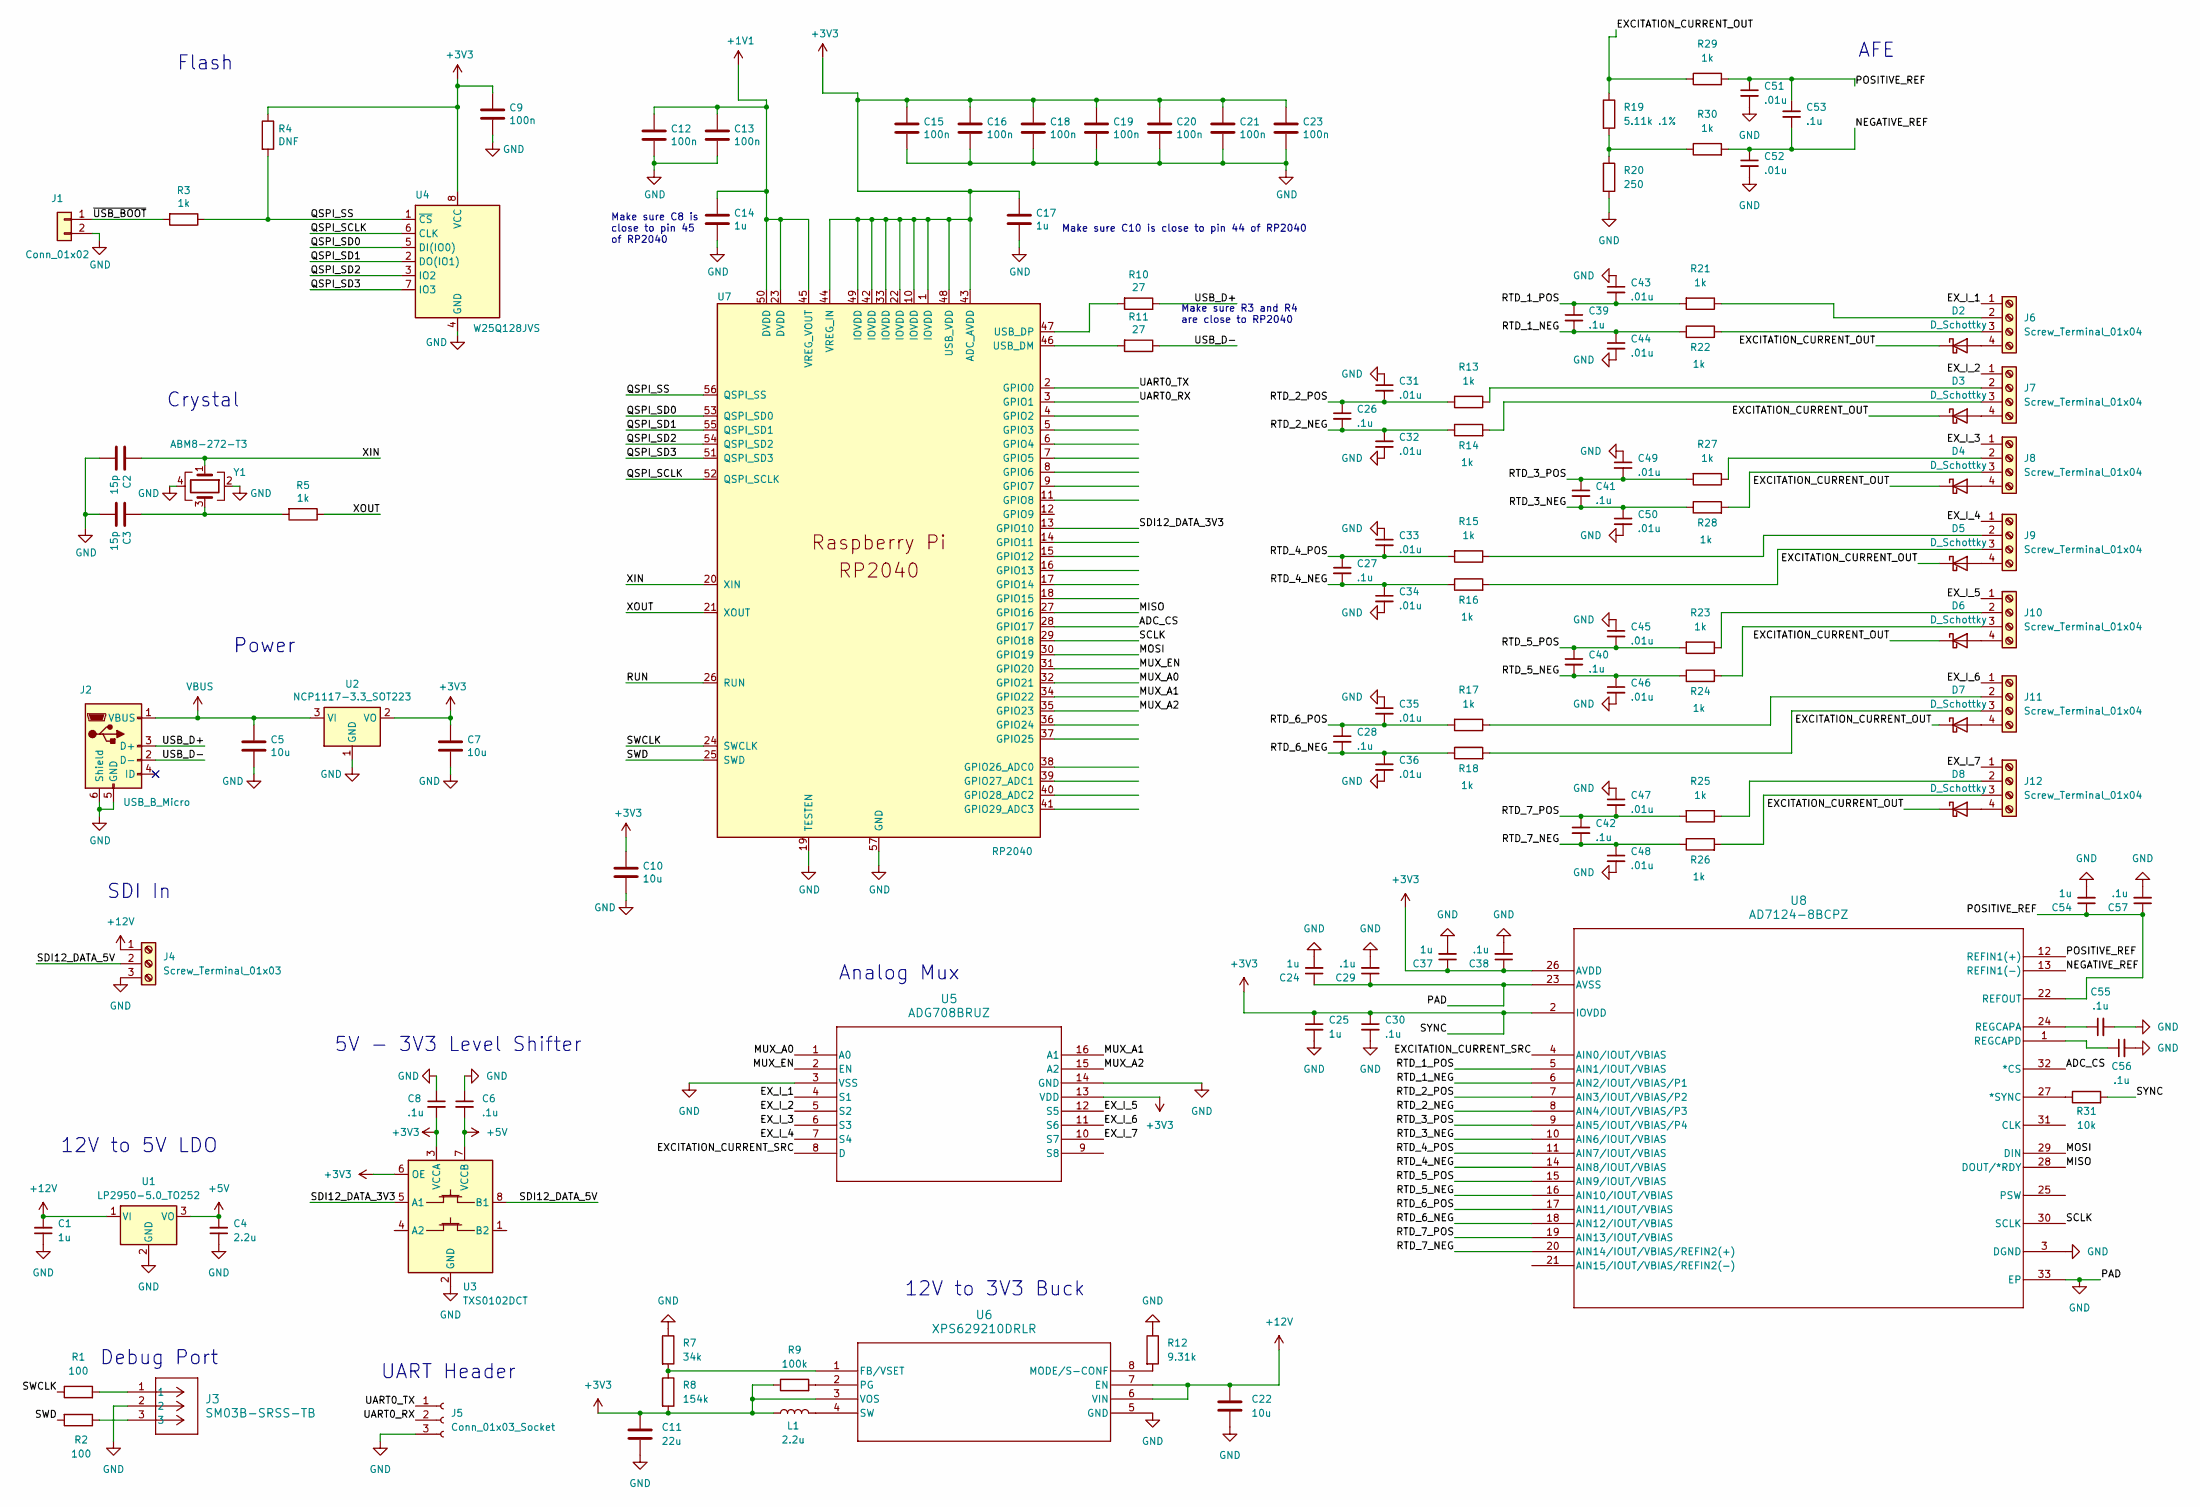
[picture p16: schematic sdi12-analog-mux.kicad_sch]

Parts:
C1, C24, C25, C37: 1u; C_0805_2012Metric
C2, C3: 15p; C_0402_1005Metric
C4: 2.2u; C_0402_1005Metric
C5, C7, C10: 10u; C_0805_2012Metric
C6, C8, C26, C27, C28, C29, C30, C38, C39, C40, C41, C42, C53, C55, C56, C57: .1u; C_0402_1005Metric
C9, C12, C13, C15, C16, C18, C19, C20, C21, C23: 100n; C_0402_1005Metric
C11: 22u; C_0402_1005Metric
C14, C17, C54: 1u; C_0402_1005Metric
C22: 10u; C_0402_1005Metric
C31, C32, C33, C34, C35, C36, C43, C44, C45, C46, C47, C48, C49, C50, C51, C52: .01u; C_0402_1005Metric
D2, D3, D4, D5, D6, D7, D8: D_Schottky; D_SOD-323F
J1: Conn_01x02; PinHeader_1x02_P2.54mm_Vertical
J2: USB_B_Micro; USB_Micro-B_Amphenol_10103594-0001LF_Horizontal_modified
J3: SM03B-SRSS-TB; CONN_SM03B-SRSS-TB_JST
J4: Screw_Terminal_01x03; TerminalBlock_Xinya_XY308-2.54-3P_1x03_P2.54mm_Horizontal
J5: Conn_01x03_Socket; PinHeader_1x03_P2.54mm_Vertical
J6, J7, J8, J9, J10, J11, J12: Screw_Terminal_01x04; TerminalBlock_Xinya_XY308-2.54-4P_1x04_P2.54mm_Horizontal
L1: 2.2u; WE-MAPI_3012
R1, R2: 100; R_0402_1005Metric
R3, R5, R13, R14, R15, R16, R17, R18, R21, R22, R23, R24, R25, R26, R27, R28, R29, R30: 1k; R_0402_1005Metric
R4: DNF; R_0402_1005Metric
R7: 34k; R_0402_1005Metric
R8: 154k; R_0402_1005Metric
R9: 100k; R_0402_1005Metric
R10, R11: 27; R_0402_1005Metric
R12: 9.31k; R_0402_1005Metric
R19: 5.11k .1%; R_0402_1005Metric
R20: 250; R_0402_1005Metric
R31: 10k; R_0402_1005Metric
U1: LP2950-5.0_TO252; TO-252-2
U2: NCP1117-3.3_SOT223; SOT-223-3_TabPin2
U3: TXS0102DCT; SSOP-8_2.95x2.8mm_P0.65mm
U4: W25Q128JVS; SOIC-8_5.23x5.23mm_P1.27mm
U5: ADG708BRUZ; RU_16_ADI
U6: XPS629210DRLR; SOT_9210DRLR_TEX-M
U7: RP2040; RP2040-QFN-56
U8: AD7124-8BCPZ; CP_32_12_ADI-M
Y1: ABM8-272-T3; Crystal_SMD_3225-4Pin_3.2x2.5mm

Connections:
+1V1: C12.1, C13.1, C14.1, U7.23 (DVDD), U7.45 (VREG_VOUT), U7.50 (DVDD)
+3V3: C7.1, C8.2, C9.1, C10.1, C11.1, C15.1, C16.1, C17.1, C18.1, C19.1, C20.1, C21.1, C23.1, C25.1, C30.1, C37.1, C38.1, L1.1, R4.1, R8.2, R9.1, R31.2, U2.2 (VO), U3.3 (VCCA), U3.6 (OE), U4.8 (VCC), U5.13 (VDD), U6.3 (VOS), U7.1 (IOVDD), U7.10 (IOVDD), U7.22 (IOVDD), U7.33 (IOVDD), U7.42 (IOVDD), U7.43 (ADC_AVDD), U7.44 (VREG_IN), U7.48 (USB_VDD), U7.49 (IOVDD), U8.2 (IOVDD), U8.26 (AVDD)
+5V: C4.2, C6.2, U1.3 (VO), U3.7 (VCCB)
+12V: C1.2, C22.1, J4.1, U1.1 (VI), U6.6 (VIN), U6.7 (EN)
/ADC_CS: U7.28 (GPIO17), U8.32 (*CS)
/EXCITATION_CURRENT_OUT: D2.1 (K), D3.1 (K), D4.1 (K), D5.1 (K), D6.1 (K), D7.1 (K), D8.1 (K), R19.1, R29.1
/EXCITATION_CURRENT_SRC: U5.8 (D), U8.4 (AIN0/IOUT/VBIAS)
/EX_I_1: J6.1, U5.4 (S1)
/EX_I_2: J7.1, U5.5 (S2)
/EX_I_3: J8.1, U5.6 (S3)
/EX_I_4: J9.1, U5.7 (S4)
/EX_I_5: J10.1, U5.12 (S5)
/EX_I_6: J11.1, U5.11 (S6)
/EX_I_7: J12.1, U5.10 (S7)
/MISO: U7.27 (GPIO16), U8.28 (DOUT/*RDY)
/MOSI: U7.30 (GPIO19), U8.29 (DIN)
/MUX_A0: U5.1 (A0), U7.32 (GPIO21)
/MUX_A1: U5.16 (A1), U7.34 (GPIO22)
/MUX_A2: U5.15 (A2), U7.35 (GPIO23)
/MUX_EN: U5.2 (EN), U7.31 (GPIO20)
/NEGATIVE_REF: C52.1, C53.2, R30.2, U8.13 (REFIN1(-))
/POSITIVE_REF: C51.1, C53.1, C54.1, C57.1, R29.2, U8.12 (REFIN1(+)), U8.22 (REFOUT)
/QSPI_SCLK: U4.6 (CLK), U7.52 (QSPI_SCLK)
/QSPI_SD0: U4.5 (DI(IO0)), U7.53 (QSPI_SD0)
/QSPI_SD1: U4.2 (DO(IO1)), U7.55 (QSPI_SD1)
/QSPI_SD2: U4.3 (IO2), U7.54 (QSPI_SD2)
/QSPI_SD3: U4.7 (IO3), U7.51 (QSPI_SD3)
/QSPI_SS: R3.1, R4.2, U4.1 (~CS), U7.56 (QSPI_SS)
/RTD_1_NEG: C39.2, C44.1, R22.1, U8.6 (AIN2/IOUT/VBIAS/P1)
/RTD_1_POS: C39.1, C43.2, R21.2, U8.5 (AIN1/IOUT/VBIAS)
/RTD_2_NEG: C26.2, C32.1, R14.1, U8.8 (AIN4/IOUT/VBIAS/P3)
/RTD_2_POS: C26.1, C31.2, R13.2, U8.7 (AIN3/IOUT/VBIAS/P2)
/RTD_3_NEG: C41.2, C50.1, R28.1, U8.10 (AIN6/IOUT/VBIAS)
/RTD_3_POS: C41.1, C49.2, R27.2, U8.9 (AIN5/IOUT/VBIAS/P4)
/RTD_4_NEG: C27.2, C34.1, R16.1, U8.14 (AIN8/IOUT/VBIAS)
/RTD_4_POS: C27.1, C33.2, R15.2, U8.11 (AIN7/IOUT/VBIAS)
/RTD_5_NEG: C40.2, C46.1, R24.1, U8.16 (AIN10/IOUT/VBIAS)
/RTD_5_POS: C40.1, C45.2, R23.2, U8.15 (AIN9/IOUT/VBIAS)
/RTD_6_NEG: C28.2, C36.1, R18.1, U8.18 (AIN12/IOUT/VBIAS)
/RTD_6_POS: C28.1, C35.2, R17.2, U8.17 (AIN11/IOUT/VBIAS)
/RTD_7_NEG: C42.2, C48.1, R26.1, U8.20 (AIN14/IOUT/VBIAS/REFIN2(+))
/RTD_7_POS: C42.1, C47.2, R25.2, U8.19 (AIN13/IOUT/VBIAS)
/RUN: U7.26 (RUN)
/SCLK: U7.29 (GPIO18), U8.30 (SCLK)
/SDI12_DATA_3V3: U3.5 (A1), U7.13 (GPIO10)
/SDI12_DATA_5V: J4.2, U3.8 (B1)
/SWCLK: R1.1, U7.24 (SWCLK)
/SWD: R2.2, U7.25 (SWD)
/UART0_RX: J5.2, U7.3 (GPIO1)
/UART0_TX: J5.1, U7.2 (GPIO0)
/USB_D+: J2.3 (D+), R10.1
/USB_D-: J2.2 (D-), R11.1
/XIN: C2.1, U7.20 (XIN), Y1.1
/XOUT: R5.1, U7.21 (XOUT)
/~USB_BOOT: J1.1, R3.2
GND: C1.1, C2.2, C3.2, C4.1, C5.2, C6.1, C7.2, C8.1, C9.2, C10.2, C11.2, C12.2, C13.2, C14.2, C15.2, C16.2, C17.2, C18.2, C19.2, C20.2, C21.2, C22.2, C23.2, C24.1, C24.2, C25.2, C29.1, C29.2, C30.2, C31.1, C32.2, C33.1, C34.2, C35.1, C36.2, C37.2, C38.2, C43.1, C44.2, C45.1, C46.2, C47.1, C48.2, C49.1, C50.2, C51.2, C52.2, C54.2, C55.2, C56.2, C57.2, J1.2, J2.5 (GND), J2.6 (Shield), J3.2, J4.3, J5.3, R7.1, R12.1, R20.2, U1.2 (GND), U2.1 (GND), U3.2 (GND), U4.4 (GND), U5.3 (VSS), U5.14 (GND), U6.5 (GND), U7.19 (TESTEN), U7.57 (GND), U8.3 (DGND), U8.23 (AVSS), U8.33 (EP), Y1.2, Y1.4
unnamed: C3.1, R5.2, Y1.3
unnamed: D2.2 (A), J6.4
unnamed: D3.2 (A), J7.4
unnamed: D4.2 (A), J8.4
unnamed: D5.2 (A), J9.4
unnamed: D6.2 (A), J10.4
unnamed: D7.2 (A), J11.4
unnamed: D8.2 (A), J12.4
unnamed: J3.1, R1.2
unnamed: J3.3, R2.1
unnamed: J6.2, R21.1
unnamed: J6.3, R22.2
unnamed: J7.2, R13.1
unnamed: J7.3, R14.2
unnamed: J8.2, R27.1
unnamed: J8.3, R28.2
unnamed: J9.2, R15.1
unnamed: J9.3, R16.2
unnamed: J10.2, R23.1
unnamed: J10.3, R24.2
unnamed: J11.2, R17.1
unnamed: J11.3, R18.2
unnamed: J12.2, R25.1
unnamed: J12.3, R26.2
unnamed: R19.2, R20.1, R30.1
unnamed: R7.2, R8.1, U6.1 (FB/VSET)
unnamed: R12.2, U6.8 (MODE/S-CONF)
unnamed: R9.2, U6.2 (PG)
unnamed: L1.2, U6.4 (SW)
unnamed: R11.2, U7.46 (USB_DM)
unnamed: R10.2, U7.47 (USB_DP)
unnamed: R31.1, U8.27 (*SYNC)
unnamed: C55.1, U8.24 (REGCAPA)
unnamed: C56.1, U8.1 (REGCAPD)
VBUS: C5.1, J2.1 (VBUS), U2.3 (VI)

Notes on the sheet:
UART Header
Power
12V to 3V3 Buck
Debug Port
5V - 3V3 Level Shifter
Crystal
Analog Mux
Flash
Make sure R3 and R4 are close to RP2040
Make sure C10 is close to pin 44 of RP2040
12V to 5V LDO
Make sure C8 is close to pin 45 of RP2040
SDI In
AFE

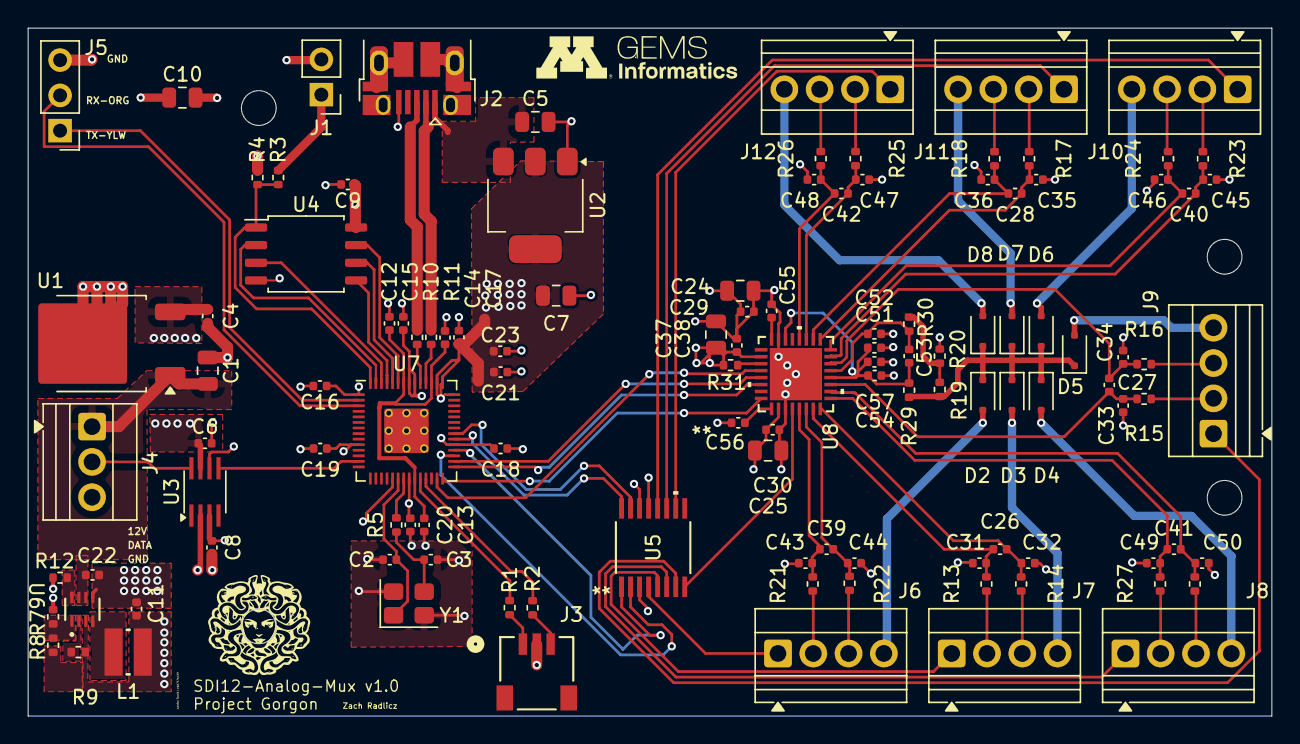
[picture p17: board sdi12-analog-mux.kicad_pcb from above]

Board: 4 copper layers, 89.5 x 49.5 mm, 118 parts (0 on the bottom side), 90 nets.

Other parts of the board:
a: LOGO
a#2: LOGO

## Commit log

2025-10-10 initial commit with somewhat routed 2 layer board
    [freerouting.dsn, sdi12-analog-mux.kicad_pcb, sdi12-analog-mux.kicad_sch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]
2025-10-17 ordered boards v0.0 and started CAD
    [PCB.FCStd, assembly.FCStd, bom.csv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]
2025-11-05 version 1.0 after v0.0 bringup modifications
    [bom.csv, designators.csv, positions.csv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]
2026-01-15 added encolsure files
    [1411133_G_INS_M20_S68N_PNES_BK-select v1.step, VENT-PS1XXX-XXXXX-STP v1.step, bottom-enclosure v17.step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]
2026-01-20 added STLs for updated enclosure
    [Bottom.stl, Cover.stl, Gasket.stl]
2026-01-26 Added Gasket dxf file
    [Gasket_Drawing.dxf]
